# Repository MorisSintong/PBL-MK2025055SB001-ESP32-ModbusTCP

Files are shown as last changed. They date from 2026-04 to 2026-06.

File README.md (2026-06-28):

# PBL-MK2025055SB001 - Face Detection & Assembly Station SCADA

Project-Based Learning (PBL) repository for a SCADA prototype built around the
**Assembly Station** at Politeknik Negeri Batam (POLIBATAM). The system uses an
**ESP32** and a **Mitsubishi FX5U PLC** as the main components, communicating
over **Modbus TCP/IP** through a W5500 Ethernet module, with a PC-based face
recognition interface acting as the human-machine interface (HMI) and access
controller.

The main objective is to develop an automatic control & monitoring system for
the Assembly Station that:

- Can be accessed over **Wi-Fi** by external devices (PC, mobile, HMI).
- Talks to the **FX5U PLC** via **Modbus TCP/IP** through the ESP32 (Modbus
  server on port 503).
- Performs **face recognition** on the PC (OpenCV/LBPH) and only allows
  authorized operators to start the machine.
- Provides a web HMI with live video feed, status indicators, and start/stop/
  emergency/reset controls.

## Repository Layout

| Path | Description |
| --- | --- |
| `Electrical-Schematics/` | KiCad project and rendered images of the electrical wiring (ESP32 + W5500 + PLC I/O). |
| `ESP32-Program/` | PlatformIO firmware for the ESP32-S3 (Wi-Fi + Ethernet + Modbus TCP server). |
| `Interface/` | Python (Flask + OpenCV) face-recognition HMI and the web/HTML front-end. |
| `README.md` | High-level block diagram of the whole system. |

## System Architecture
```mermaid
graph TD
    Camera[Camera]
    PC[PC]
    PLC[PLC FX5U]
    Wago[Wago I/O Module]
    ExternalDevice[External Device]
    Output[Output]

    subgraph ESP32Container [ESP-32 Physical Device]
        ESP32Core(ESP-32)
        subgraph HostedServices [Hosted Services]
            WebServer[Web Server]
        end
    end

    Camera ---|USB-Serial| PC
    PC ---|HTTP Wi-Fi| ESP32Core
    Wago --- Output

    PLC ===|Modbus TCP/IP PLC=Client, ESP-32=Server| ESP32Core
    PLC ===|Modbus TCP/IP PLC=Client, Wago=Server| Wago

    WebServer -.->|Wi-Fi| ExternalDevice
```

## System Overview

1. **Interface (PC)** runs a Flask web app (`Interface/app.py`) that:
   - Captures the webcam feed and detects faces using Haar cascade.
   - Recognizes the operator using an LBPH model (`trainer/trainer.yml`).
   - On authorized detection, sends HTTP commands to the ESP32
     (`/action?type=start|stop|emergency|reset`).
2. **ESP32** (`ESP32-Program/src/main.cpp`) runs two FreeRTOS tasks:
   - **Core 0** – Wi-Fi + WebServer (receives commands from the PC interface).
   - **Core 1** – W5500 Ethernet + Modbus TCP server (port 503) that writes the
     command coils read by the FX5U PLC and reads status coils from the PLC.
3. **Mitsubishi FX5U PLC** is the Modbus TCP client that controls the Assembly
   Station actuators based on the ESP32 coils.

See the [System Architecture](#system-architecture) section for the full block diagram and the per-directory
`README.md` files for component-level details.

## Quick Start

1. Build and flash the firmware with PlatformIO:
   ```bash
   cd ESP32-Program
   pio run -t upload
   ```
2. Train the face model from the PC interface:
   ```bash
   cd Interface
   python 01_Ambil_Wajah.py   # capture dataset
   python 02_training.py      # train -> trainer/trainer.yml
   ```
3. Launch the web HMI:
   ```bash
   python app.py              # http://<PC-IP>:5000
   ```
4. Configure the PLC (FX5U) Modbus TCP client to connect to the ESP32 Ethernet
   IP (`192.168.1.50:503`) and read/write the coils listed in
   `ESP32-Program/src/main.cpp`.

## Finieshed Product & Implementation
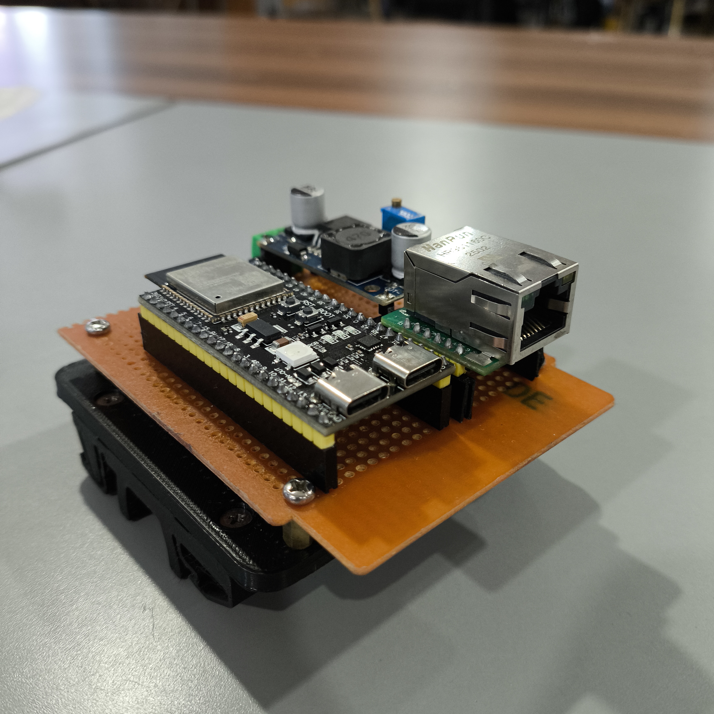
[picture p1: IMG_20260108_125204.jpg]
Finished PCB

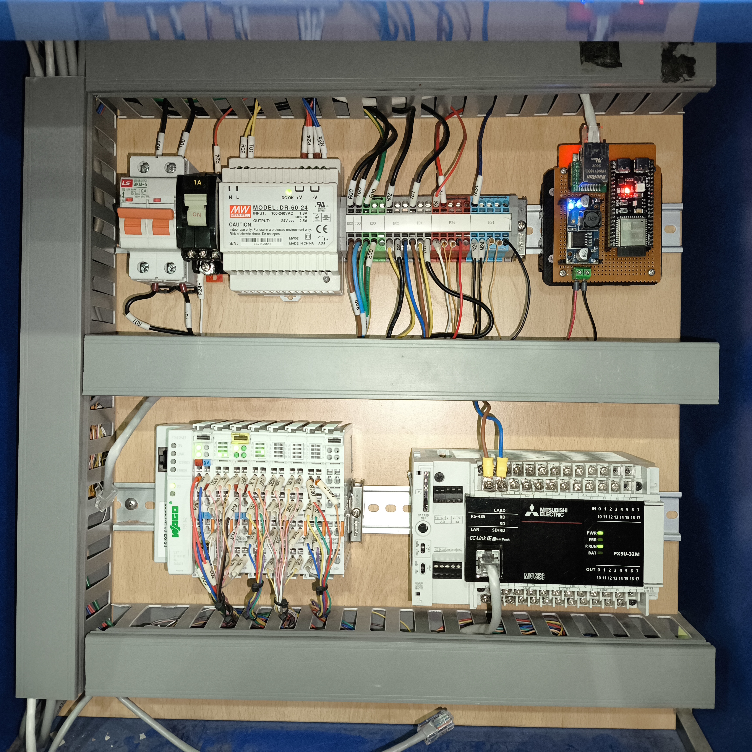
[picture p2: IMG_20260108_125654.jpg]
Implementation


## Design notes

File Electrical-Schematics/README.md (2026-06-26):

# Electrical-Schematics

This folder holds the electrical documentation for the PBL Assembly Station
control panel. It contains both the source KiCad project (editable) and the
exported/rendered images used in the report and README.

## Preview

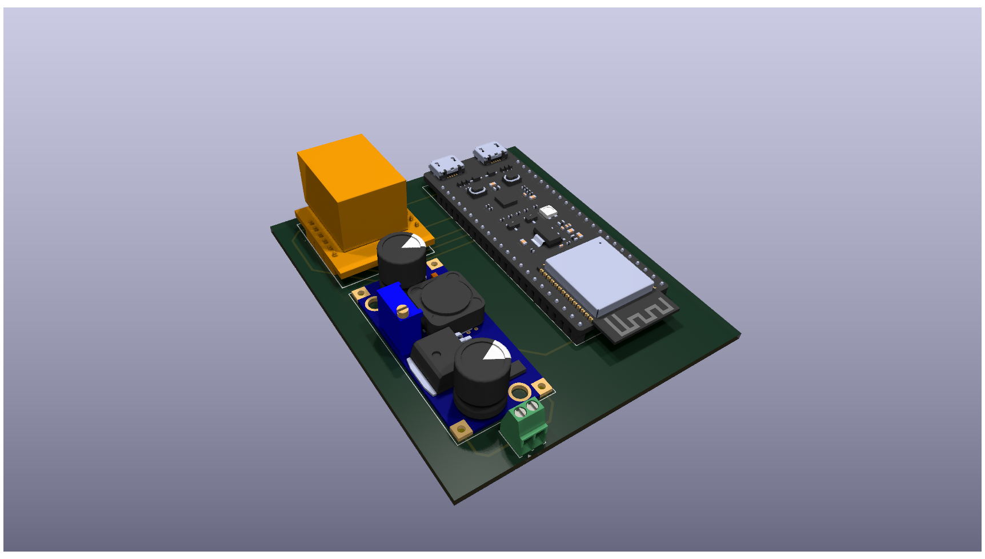
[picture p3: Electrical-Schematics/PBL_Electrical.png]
PBL Electrical


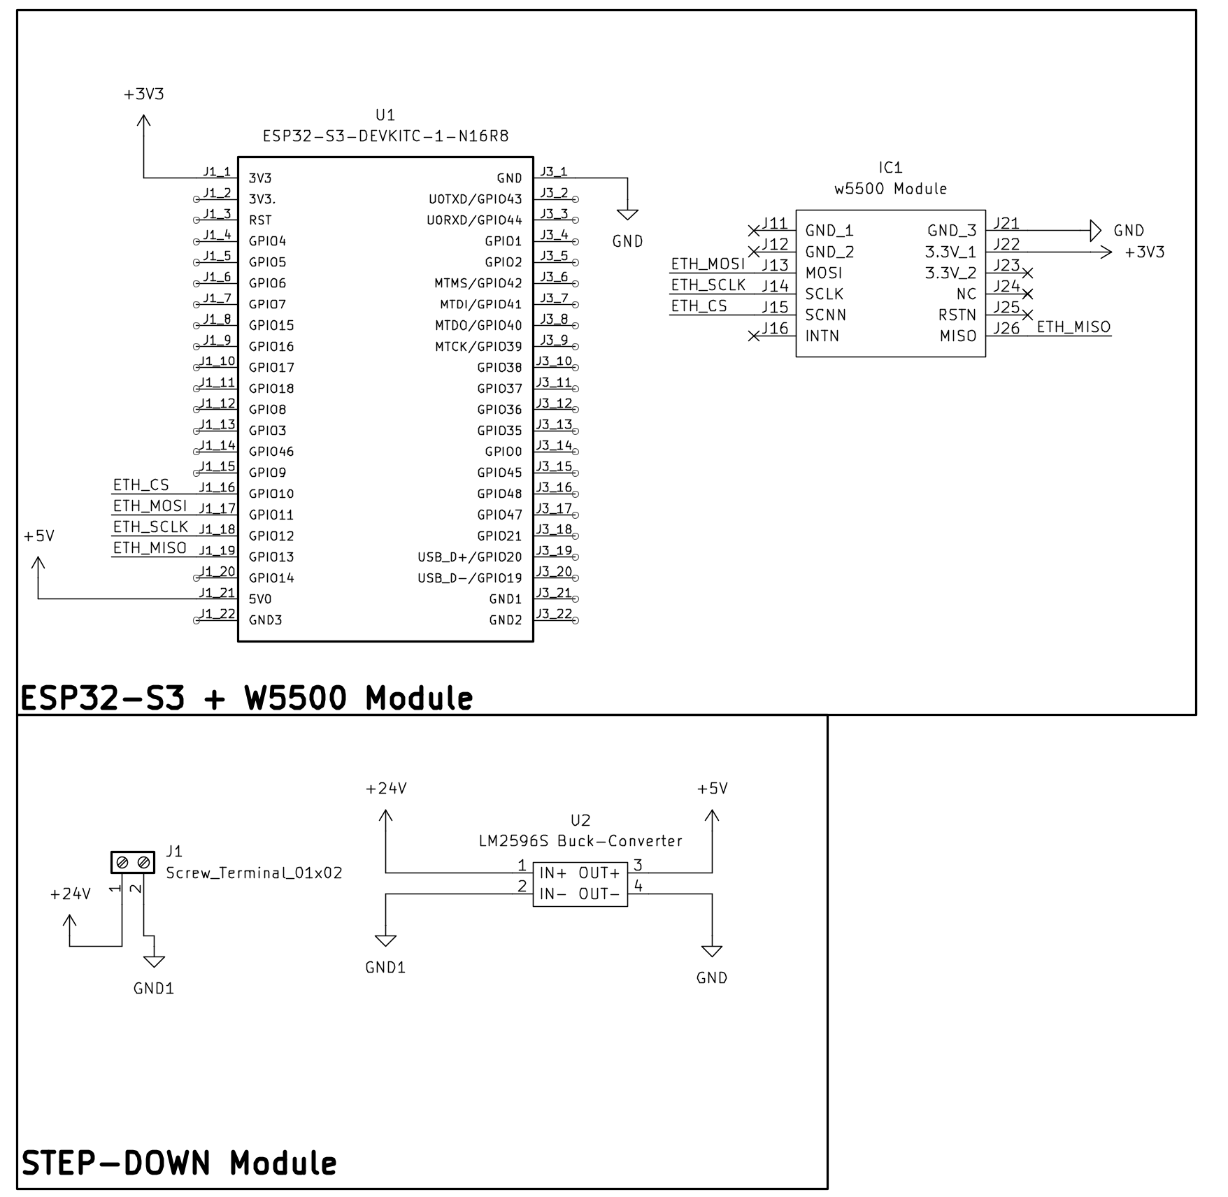
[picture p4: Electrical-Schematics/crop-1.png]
Crop 1


## Contents

- `PBL_Electrical.png` – Full rendered schematic/PCB image of the electrical
  wiring (ESP32-S3 + W5500 Ethernet module + PLC I/O + power supply).
- `crop-1.png` – Cropped close-up of a section of the schematic used in
  documentation.
- `PBL_Electrical_KiCad/` – The full KiCad project (schematic, PCB, symbols,
  3D model, footprints). See its own `README.md` for details.

## What it represents

The schematic wires:

- **ESP32-S3 DevKit** to the **W5500** over SPI (CS=10, MOSI=11, SCLK=12,
  MISO=13) for the Modbus TCP Ethernet link to the FX5U PLC.
- Power supply / protection blocks for the ESP32 and the Ethernet module.
- I/O routing between the ESP32 coils and the PLC digital inputs/outputs.

Use this as the wiring reference when assembling or troubleshooting the
hardware. The same pin assignments must match those defined in
`ESP32-Program/src/main.cpp`.

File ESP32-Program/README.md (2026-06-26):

# ESP32-Program

PlatformIO firmware project for the **ESP32-S3 DevKitC-1**. The firmware turns
the ESP32 into a protocol bridge between the PC face-recognition interface and
the Mitsubishi FX5U PLC:

- **Wi-Fi (Core 0)** – runs a `WebServer` that receives HTTP commands from the
  Python HMI (`/action`, `/status`, `/user_detection`).
- **Ethernet + Modbus TCP (Core 1)** – drives a W5500 module over SPI and runs
  a Modbus TCP server on **port 503** that the FX5U PLC reads/writes.

## Structure

- `platformio.ini` – PlatformIO configuration (board `esp32-s3-devkitc-1`,
  Arduino framework, PSRAM enabled, libraries: `Ethernet_Generic`,
  `modbus-esp8266`).
- `src/` – Application source code (`main.cpp`).
- `include/` – Project header files (currently empty/PlatformIO default).
- `lib/` – Project-specific (private) libraries (currently empty).
- `test/` – PlatformIO unit tests (currently empty).

## Build & flash

```bash
pio run -t upload
pio device monitor   # 921600 baud
```

## Modbus coil map (defined in `src/main.cpp`)

| Coil | Address | Direction | Description |
| --- | --- | --- | --- |
| BTN 1 (Start) | 112 | PC -> PLC | Momentary start command |
| BTN 2 (Stop) | 113 | PC -> PLC | Momentary stop command |
| BTN 3 (Emergency)| 114 | PC -> PLC | Momentary emergency command |
| BTN 4 (Reset) | 115 | PC -> PLC | Momentary reset command |
| User Detected | 116 | PC -> PLC | Face-recognition authorized flag |
| STS_RUNNING | 208 | PLC -> PC | Machine running indicator |
| STS_STOPPED | 209 | PLC -> PC | Machine stopped indicator |
| STS_EMG | 210 | PLC -> PC | Emergency active indicator |

Default Ethernet IP: `192.168.1.50`. Wi-Fi IP is configured statically inside
`main.cpp` (default `10.251.64.200`) – change these to match your network.

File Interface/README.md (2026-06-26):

# Interface

PC-side HMI and face-recognition application. The interface is written in
Python (Flask + OpenCV) and provides:

- A browser-based HMI with the live webcam feed, start/stop/emergency/reset
  buttons, and PLC status indicators.
- Face **detection** (Haar cascade) and **recognition** (LBPH) to authorize
  operators before the machine can be started.
- HTTP communication with the ESP32 web server to forward commands to the PLC.
- CSV timing logs for performance measurement.

## Main scripts

| File | Purpose |
| --- | --- |
| `app.py` | Primary Flask web HMI: video feed, face recognition, training, registration, PLC command forwarding. **Run this for the production interface.** |
| `AppImproved.py` | Performance-optimized variant of `app.py` (threaded `VideoStream`, lower JPEG quality, etc.). |
| `main.py` | Standalone Tkinter desktop GUI version of the HMI (no browser needed). |
| `pythonUDP.py` | Experimental variant that sends commands to the ESP32 over UDP instead of HTTP. |
| `01_Ambil_Wajah.py` | CLI tool to capture face images into `dataset/` for a given user ID. |
| `02_training.py` | CLI tool to train the LBPH model from `dataset/` into `trainer/trainer.yml`. |
| `test_modbus.py` | Standalone Modbus TCP client test to verify the ESP32 coils (connects to `192.168.1.50:503`). |

## Subdirectories

- `templates/` – Jinja2 HTML templates for the Flask HMI.
- `GUI/` – Stand-alone Arduino sketch (`GUI_REAL.ino`) for an early prototype
  that put the web HMI directly on a second ESP32.
- `dataset/` – Captured face images (`User.<id>.<n>.jpg`).
- `trainer/` – Trained LBPH model (`trainer.yml`).
- `Timings_log/` – Recorded timing CSVs from earlier test runs.

## Running

```bash
# 1. Capture faces (optional, or use the web HMI registration button)
python 01_Ambil_Wajah.py
# 2. Train the model
python 02_training.py
# 3. Launch the web HMI
python app.py          # open http://<PC-IP>:5000
```

Make sure the ESP32 IP inside each script matches the ESP32's actual Wi-Fi IP
(`ESP32_IP = "http://<IP>"`).

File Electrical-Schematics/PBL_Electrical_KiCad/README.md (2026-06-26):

# PBL_Electrical_KiCad

Native KiCad project for the PBL Assembly Station electrical schematic and PCB.

## Preview

PBL Electrical

## Key files

- `PBL_Electrical.kicad_pro` – KiCad project file (open this in KiCad).
- `PBL_Electrical.kicad_sch` – Schematic sheet.
- `PBL_Electrical.kicad_pcb` – PCB layout.
- `PBL_Electrical.kicad_prl` – KiCad project local settings.
- `PBL_Proj.bak` / `PBL_Proj-sem5.pretty/` / `PBL_Proj.kicad_sym` – Project
  symbol library, custom footprint library, and backups.
- `fp-info-cache`, `fp-lib-table`, `sym-lib-table` – KiCad library tables.
- `PBL_Electrical.png` – Rendered preview of the board/schematic.
- `PBL_Electrical.step` / `PBL_Electrical.wrl` – 3D model exports for CAD.
- `3d.pcb3d` – KiCad 3D viewer cache.
- `PBL_Electrical-backups/` – Automatic KiCad backups.

## How to use

1. Open `PBL_Electrical.kicad_pro` in **KiCad 6+**.
2. Edit the schematic / PCB as needed.
3. Re-export `PBL_Electrical.png` and the 3D models, then update the parent
   `Electrical-Schematics/` images if the wiring changes.

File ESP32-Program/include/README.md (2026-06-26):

# include

Reserved for project-wide C/C++ header files (`.h`) shared across the source
files in `../src`. Currently empty (no extra headers needed); the firmware in
`src/main.cpp` only includes library headers at this time.

PlatformIO automatically adds this directory to the include path, so any
header placed here can be included as `#include "myheader.h"`.

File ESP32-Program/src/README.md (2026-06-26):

# src

Main application source for the ESP32 firmware.

## Files

- `main.cpp` – The complete firmware entry point. It:
  - Initializes SPI for the W5500 Ethernet module and starts a Modbus TCP
    server on port 503.
  - Spawns two pinned FreeRTOS tasks:
    - `modbusTask` (Core 1, priority 2) – poll Modbus, process command flags,
      handle momentary coil timers, monitor W5500 socket/Ethernet link.
    - `wifiTask` (Core 0, priority 1) – connect to Wi-Fi with a static IP,
      start mDNS (`esp32-server.local`), serve the HTTP endpoints used by the
      PC interface, and auto-reconnect on Wi-Fi loss.
  - Exposes HTTP endpoints: `/`, `/status`, `/action?type=...`,
    `/user_detection?detected=1|0`.
  - Uses `std::atomic` flags + a Serial mutex for safe cross-core access.
- `src.7z` – Archive backup of previous source revisions.

To rebuild, run `pio run -t upload` from the parent `ESP32-Program/` directory.

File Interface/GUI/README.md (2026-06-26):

# GUI

Early-prototype GUI option that hosts a minimal web interface directly on a
separate ESP32 (instead of on the PC). Kept for reference/history.

## Contents

- `GUI_REAL/` – Arduino sketch (`GUI_REAL.ino`) that creates a Wi-Fi AP named
  `MEKAPBL` with password `mekagui1` and exposes `/action?type=...`
  endpoints to print `start` / `stop` / `emergency` / `reset` to the serial
  monitor (placeholder for driving relays/LEDs). See its `README.md`.

This prototype was later replaced by the PC-side Flask HMI in the parent
`Interface/` directory (`app.py`), which also performs face recognition.

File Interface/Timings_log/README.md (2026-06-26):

# Timings_log

Archived timing measurements from earlier interface/ESP32 round-trip tests.
Each CSV records `timestamp, source, command, duration_ms, success,
internal_latency_us` rows produced by the `_log_timing_csv` helper in the
interface scripts.

## Files

- `timings.csv` – General run log (default output path used by the scripts).
- `timings1.csv`, `timings2.csv` – Additional runs captured during testing.
- `timings_Jauh.csv` – Tests performed with a larger physical distance between
  the PC/ESP32 and the PLC (latency under range/relay conditions).

These files are kept for reference and for plotting performance in the project
report. New runs will recreate `timings.csv` in the `Interface/` working
directory unless the `_csv_path` variable is changed inside the scripts.

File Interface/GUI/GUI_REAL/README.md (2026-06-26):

# GUI_REAL

Arduino sketch for the early-prototype stand-alone ESP32 web HMI.

## `GUI_REAL.ino`

- Creates a Wi-Fi **Access Point** (`MEKAPBL` / `mekagui1`).
- Starts a `WebServer` on port 80 with the `/action?type=...` route.
- Accepts `start`, `stop`, `emergency`, `reset` commands and currently
  serial-prints the corresponding status (placeholder for driving
  relays/LEDs/actuators).
- Responds with `OK - <type>` on success or `Error` if the `type` argument is
  missing.

This was an initial feasibility prototype. The final system instead runs the
HMI on the PC (`Interface/app.py`) and uses this ESP32 only for face-gated
command forwarding; the production firmware lives in `ESP32-Program/`.

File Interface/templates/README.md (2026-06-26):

# templates

Jinja2 HTML templates rendered by the Flask HMI in the parent `Interface/`
directory.

## Files

- `index.html` – Single-page HMI shown to the operator. It contains:
  - An MJPEG `<img>` element pointing at `/video_feed` for the live webcam
    stream with face-detection overlays.
  - A colored status bar (Access Granted / Denied / System Stop).
  - Start / Stop / Emergency / Reset control buttons that issue fetch
    requests to the Flask routes (`/command/<cmd>`).
  - A poller to `/check_status` that updates PLC running/stopped/emergency
    indicators and the connection state.
  - Operator registration & model-training UI.

This file is served by the `/` route in `app.py` / `AppImproved.py`.

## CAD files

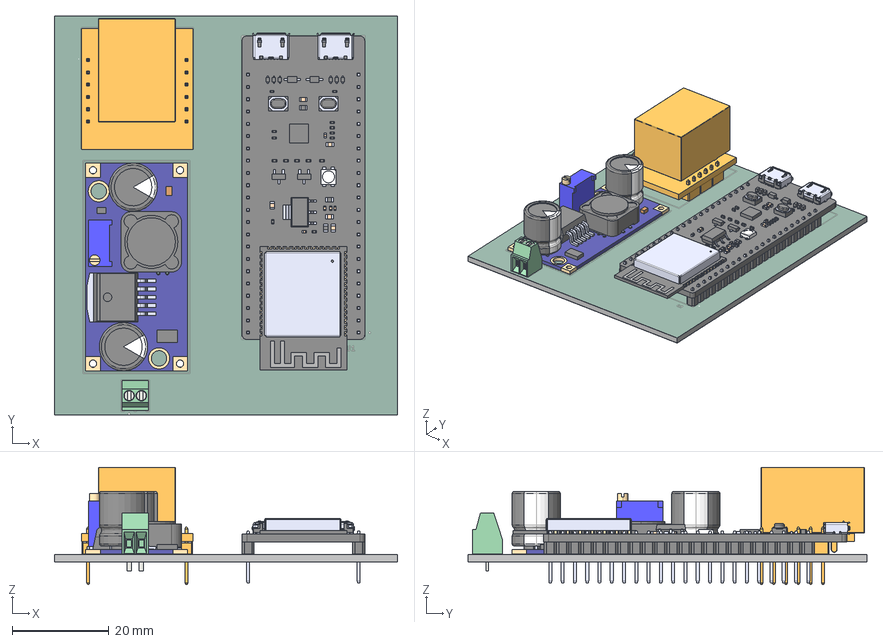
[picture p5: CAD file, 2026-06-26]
Electrical-Schematics/PBL_Electrical_KiCad/PBL_Electrical.step
71.0 x 82.5 x 24.3 mm
MC00100
3296W-1-104
DR125-331-R
EEUTA1V221 x 2
LM2596DSADJG
ESP32-S3-DEVKITC-1-N8R8
TerminalBlock_Phoenix_MPT-0,5-2-2.54_1x02_P2.54mm_Horizontal
WIZ850IO
PBL_Electrical_copper
PBL_Electrical_pad
PBL_Electrical_via
PBL_Electrical_silkscreen
PBL_Electrical_soldermask x 2
PBL_Electrical_PCB

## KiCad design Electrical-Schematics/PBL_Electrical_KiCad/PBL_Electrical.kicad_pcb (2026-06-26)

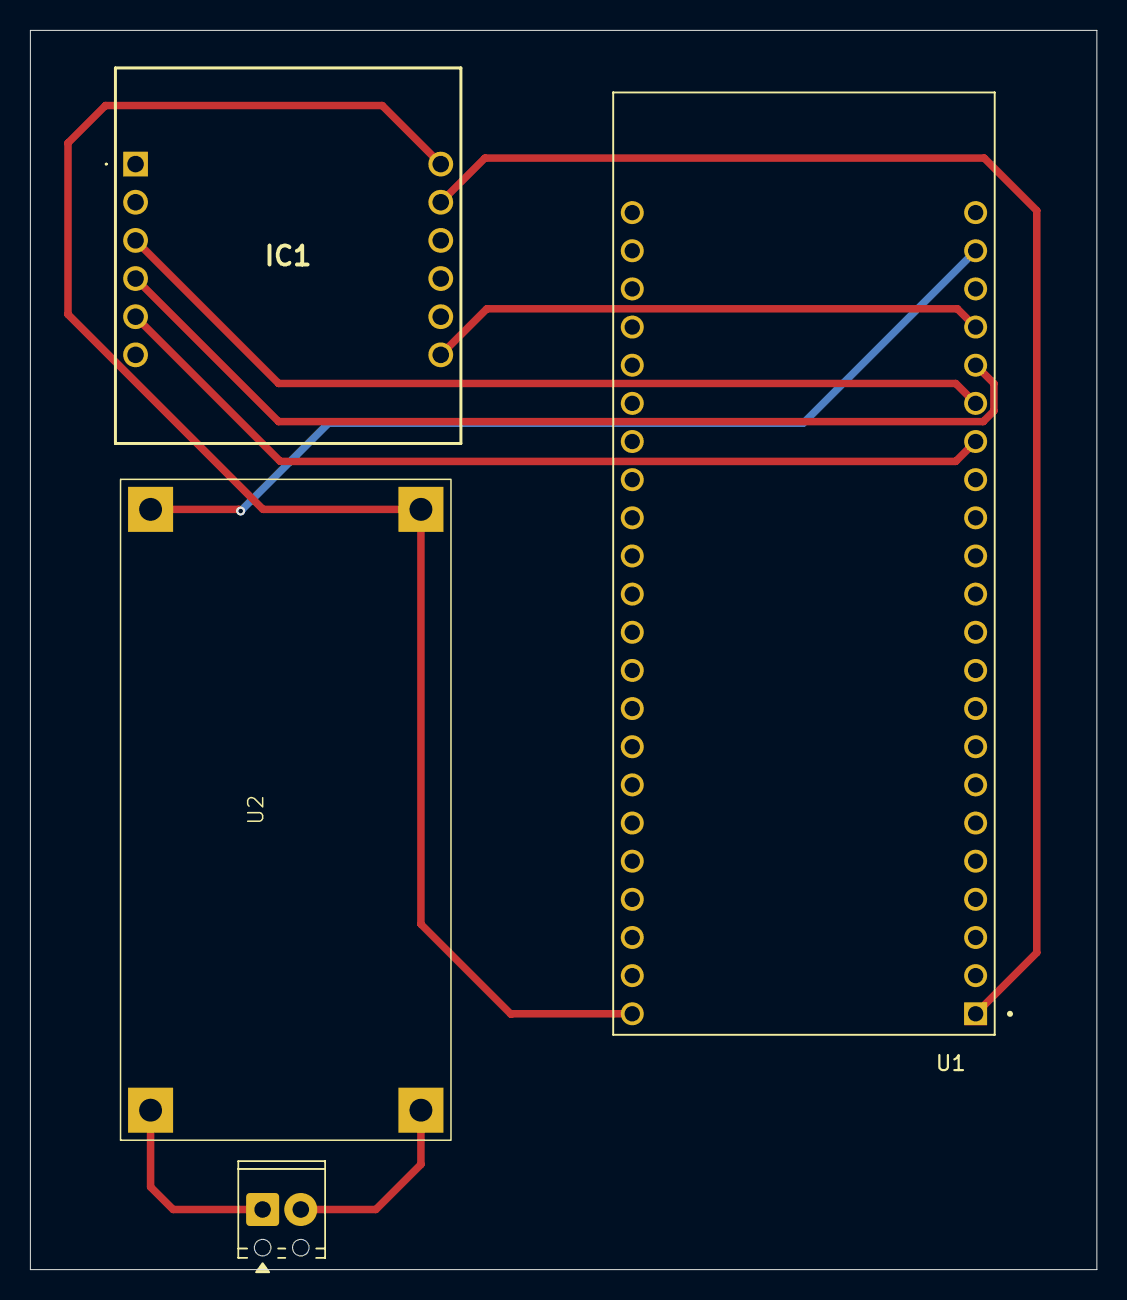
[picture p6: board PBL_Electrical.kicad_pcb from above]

Board: 2 copper layers, 71.0 x 82.5 mm, 4 parts (0 on the bottom side), 9 nets.

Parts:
IC1: w5500 Module; WIZ850IO
J1: Screw_Terminal_01x02; TerminalBlock_Phoenix_MPT-0,5-2-2.54_1x02_P2.54mm_Horizontal
U1: ESP32-S3-DEVKITC-1-N16R8; ESP32-S3-DEVKITC-1-N8R8
U2: LM2586S Buck-Converter; Untitled

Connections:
+3V3: IC1.J22 (3.3V_1), U1.J1_1 (3V3)
+5V: U1.J1_21 (5V0), U2.3 (OUT+)
+24V: J1.1, U2.1 (IN+)
/ETH_CS: IC1.J15 (SCNN), U1.J1_16 (GPIO10)
/ETH_MISO: IC1.J26 (MISO), U1.J1_19 (GPIO13)
/ETH_MOSI: IC1.J13 (MOSI), U1.J1_17 (GPIO11)
/ETH_SCLK: IC1.J14 (SCLK), U1.J1_18 (GPIO12)
GND: IC1.J21 (GND_3), U1.J3_1 (GND), U2.4 (OUT-)
GND1: J1.2, U2.2 (IN-)

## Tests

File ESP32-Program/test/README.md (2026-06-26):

# test

Reserved for PlatformIO unit tests for the ESP32 firmware. Tests placed here
(e.g. `test/test_main.cpp`) are run with `pio test` on the target hardware or
under a native simulator depending on the environment configuration.

Currently empty – no automated tests have been written yet. Manual validation
is performed through the serial monitor and the `test_modbus.py` script in the
`Interface/` directory.

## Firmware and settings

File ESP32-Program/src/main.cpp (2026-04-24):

#include <Arduino.h>
#include <WiFi.h>
#include <ESPmDNS.h>
#include <WebServer.h>
#include <SPI.h>
#include <Ethernet_Generic.h>
#include <ModbusEthernet.h>
#include <atomic> // REQUIRED for thread safety



// =======================================================================
// USER CONFIGURATION
// =======================================================================

const char* ssid = "TestEsp32";
const char* password = "12345678";

// W5500 Pins
constexpr uint8_t ETH_CS_PIN = 10;
constexpr uint8_t ETH_MOSI_PIN = 11;
constexpr uint8_t ETH_SCLK_PIN = 12;
constexpr uint8_t ETH_MISO_PIN = 13;


// Ethernet Network Settings
// IMPORTANT: Use a unique MAC address to avoid ARP conflicts
byte macAddress[] = {0x02, 0xAB, 0xCD, 0x01, 0x02, 0x03};
IPAddress staticIp(192, 168, 1, 50);
IPAddress staticGateway(192, 168, 1, 1);
IPAddress staticSubnet(255, 255, 255, 0);
IPAddress staticDns(192, 168, 1, 1);

// Modbus Coils (Buttons)
const uint16_t COIL_BTN_1 = 112;
const uint16_t COIL_BTN_2 = 113;
const uint16_t COIL_BTN_3 = 114;
const uint16_t COIL_BTN_4 = 115;

// Modbus Coil (User Detection Status - Written by Face Recognition System)
const uint16_t COIL_USER_DETECTED = 116;

// Modbus Coils (Status Indicators - Read from PLC)
const uint16_t STS_RUNNING = 208;
const uint16_t STS_STOPPED = 209;
const uint16_t STS_EMG     = 210;

// Shared Variables (Atomic for thread safety)
std::atomic<bool> reqBtn1(false);
std::atomic<bool> reqBtn2(false);
std::atomic<bool> reqBtn3(false);
std::atomic<bool> reqReset(false);
std::atomic<unsigned long> actionStartTime(0);
std::atomic<unsigned long> lastInternalLatencyUs(0);

// User Detection Status (from Face Recognition System)
std::atomic<bool> userDetected(false);
std::atomic<bool> userDetectedChanged(false);

volatile unsigned long timerBtn1 = 0;
volatile unsigned long timerBtn2 = 0;
volatile unsigned long timerBtn3 = 0;
volatile unsigned long timerBtn4 = 0;
const unsigned long MOMENTARY_DELAY = 500; 

// Objects
WebServer server(80);
ModbusEthernet mb;
SemaphoreHandle_t serialMutex; // Mutex for Serial safety

// Modbus Activity Counters (for real tracking)
volatile uint32_t modbusConnections = 0;
volatile uint32_t modbusDisconnections = 0;

// Task Handles
TaskHandle_t ModbusTaskHandle;
TaskHandle_t WifiTaskHandle;

// Forward declaration for callbacks
void safePrintln(const String &msg);

// Modbus Callbacks
bool onModbusConnect(IPAddress ip) {
  modbusConnections++;
  Serial.print("[Modbus] >>> Client CONNECTED from: ");
  Serial.println(ip);
  return true;  // Accept connection
}

// Helper for safe printing
void safePrintln(const String &msg) {
  if (xSemaphoreTake(serialMutex, portMAX_DELAY)) {
    Serial.println(msg);
    xSemaphoreGive(serialMutex);
  }
}


// =======================================================================
// WEB SERVER FUNCTIONS (Run on Core 0) 
// =======================================================================

void handleRoot() {
  server.send(200, "text/plain", "ESP32 Opti-Server Online");
}

void handleStatus() {
  // Read Modbus Coils (Thread-safe enough for bool read)
  bool running = mb.Coil(STS_RUNNING);
  bool stopped = mb.Coil(STS_STOPPED);
  bool emg     = mb.Coil(STS_EMG);
  unsigned long lastLatency = lastInternalLatencyUs;

  String json = "{";
  json += "\"running\":" + String(running ? "true" : "false") + ",";
  json += "\"stopped\":" + String(stopped ? "true" : "false") + ",";
  json += "\"emergency\":" + String(emg ? "true" : "false") + ",";
  json += "\"last_internal_latency_us\":" + String(lastLatency);
  json += "}";

  server.send(200, "application/json", json);
}

void handleAction() {
  if (!server.hasArg("type")) {
    server.send(400, "text/plain", "Missing type");
    safePrintln("[Web] Error: Missing type argument");
    return;
  }
  String type = server.arg("type");
  safePrintln("[Web] Received command: " + type);
  
  // THREAD-SAFE FIX:
  // Instead of calling mb.Coil() directly (which is dangerous across cores),
  // we just set a flag. The Modbus Task (Core 1) will pick it up safely.
  
  actionStartTime = micros();

  if (type == "start") {
    reqBtn1 = true;
  } else if (type == "stop") {
    reqBtn2 = true;
  } else if (type == "emergency") {
    reqBtn3 = true;
  } else if (type == "reset") {
    reqReset = true;
  } else {
    server.send(400, "text/plain", "Unknown command");
    return;
  }
  server.send(200, "text/plain", "OK");
}

// Handler for User Detection Status from Face Recognition System
void handleUserDetection() {
  if (!server.hasArg("detected")) {
    server.send(400, "text/plain", "Missing detected parameter");
    return;
  }
  String detected = server.arg("detected");
  bool newState = (detected == "1" || detected == "true");
  
  // Only update if state changed
  if (userDetected != newState) {
    userDetected = newState;
    userDetectedChanged = true;
    safePrintln("[Web] User detection: " + String(newState ? "DETECTED" : "NOT DETECTED"));
  }
  
  server.send(200, "text/plain", "OK");
}

// =======================================================================
// FREERTOS TASKS
// =======================================================================

// Task 1: Modbus & Ethernet (High Priority, Core 1)
void modbusTask(void * parameter) {
  // Modbus is already initialized in setup() for faster response
  // This task just runs mb.task() in a loop

  safePrintln("[Core 1] Modbus task running");

  static unsigned long lastLinkCheck = 0;
  static unsigned long lastSocketCheck = 0;

  for (;;) {
    // 0. Check Ethernet Link and Socket Status
    if (millis() - lastLinkCheck > 2000) {
        lastLinkCheck = millis();
        EthernetLinkStatus linkStatus = Ethernet.linkStatus();
        if (linkStatus == LinkOFF) {
             safePrintln("[Core 1] !!! Ethernet Link OFF !!!");
        } else if (linkStatus == Unknown) {
             safePrintln("[Core 1] Ethernet Link: Unknown");
        }
    }
    
    // 0b. Monitor Modbus Connections and W5500 Socket Status
    if (millis() - lastSocketCheck > 3000) {
        lastSocketCheck = millis();
        Ethernet.maintain(); // Force socket cleanup
        
        // Report actual Modbus TCP connections
        safePrintln("[Core 1] Connections: " + String(modbusConnections) + " | Link: " + 
                   (Ethernet.linkStatus() == LinkON ? "ON" : "OFF"));
        
        // Print W5500 socket status for debugging
        Serial.print("[W5500 Sockets] ");
        for (int i = 0; i < 8; i++) {
            uint8_t status = W5100.readSnSR(i);
            Serial.print(i);
            Serial.print(":");
            Serial.print(status, HEX);
            Serial.print(" ");
        }
        Serial.println();
    }
    // 1. PROCESS FLAGS (Thread-Safe Write)
    if (reqBtn1) {
      mb.Coil(COIL_BTN_1, true);
      timerBtn1 = millis();
      reqBtn1 = false;
      unsigned long latency = micros() - actionStartTime;
      lastInternalLatencyUs.store(latency);
      safePrintln("BTN 1 Triggered. Latency: " + String(latency) + " us");
    }
    if (reqBtn2) {
      mb.Coil(COIL_BTN_2, true);
      timerBtn2 = millis();
      reqBtn2 = false;
      unsigned long latency = micros() - actionStartTime;
      lastInternalLatencyUs.store(latency);
      safePrintln("BTN 2 Triggered. Latency: " + String(latency) + " us");
    }
    if (reqBtn3) {
      mb.Coil(COIL_BTN_3, true);
      timerBtn3 = millis();
      reqBtn3 = false;
      unsigned long latency = micros() - actionStartTime;
      lastInternalLatencyUs.store(latency);
      safePrintln("BTN 3 Triggered. Latency: " + String(latency) + " us");
    }
    if (reqReset) {
      mb.Coil(COIL_BTN_4, true);
      timerBtn4 = millis();
      reqReset = false;
      unsigned long latency = micros() - actionStartTime;
      lastInternalLatencyUs.store(latency);
      safePrintln("Reset Triggered. Latency: " + String(latency) + " us");
    }

    // 1b. PROCESS USER DETECTION (Continuous coil, not momentary)
    if (userDetectedChanged) {
      bool detected = userDetected.load();
      mb.Coil(COIL_USER_DETECTED, detected);
      userDetectedChanged = false;
      safePrintln("User Detection Coil: " + String(detected ? "HIGH" : "LOW"));
    }

    // 2. Run Modbus Task
    mb.task();

    // 3. Handle Timers
    unsigned long now = millis();
    if (timerBtn1 > 0 && now - timerBtn1 > MOMENTARY_DELAY) {
      mb.Coil(COIL_BTN_1, false);
      timerBtn1 = 0;
    }
    if (timerBtn2 > 0 && now - timerBtn2 > MOMENTARY_DELAY) {
      mb.Coil(COIL_BTN_2, false);
      timerBtn2 = 0;
    }
    if (timerBtn3 > 0 && now - timerBtn3 > MOMENTARY_DELAY) {
      mb.Coil(COIL_BTN_3, false);
      timerBtn3 = 0;
    }
    if (timerBtn4 > 0 && now - timerBtn4 > MOMENTARY_DELAY) {
      mb.Coil(COIL_BTN_4, false);
      timerBtn4 = 0;
    }

    // Small yield
    vTaskDelay(1 / portTICK_PERIOD_MS); 
  }
}

// Task 2: Wi-Fi & Web Server (Lower Priority, Core 0)
void wifiTask(void * parameter) {
  safePrintln("[Core 0] Wi-Fi Task Started");
  
  // OPTIMIZATION: Disable Power Save for low latency HTTP response
  WiFi.setSleep(false);
  
  // --- STATIC IP CONFIGURATION ---
  // Must be called BEFORE WiFi.begin()
  IPAddress wifiIp(10, 251, 64, 200);       
  IPAddress wifiGateway(10, 251, 64, 8);
  IPAddress wifiSubnet(255, 255, 255, 0);
  IPAddress wifiDns(10, 251, 64, 8);
  
  if (!WiFi.config(wifiIp, wifiGateway, wifiSubnet, wifiDns)) {
    safePrintln("[Core 0] Error: Failed to configure Static IP!");
  }
  // ------------------------------------

  WiFi.begin(ssid, password);
  while (WiFi.status() != WL_CONNECTED) {
    Serial.print(".");
    vTaskDelay(500 / portTICK_PERIOD_MS);
  }
  Serial.println("");

  safePrintln("[Core 0] Wi-Fi IP: " + WiFi.localIP().toString());

  if (MDNS.begin("esp32-server")) {
    safePrintln("[Core 0] mDNS responder started: http://esp32-server.local");
  }

  server.on("/", handleRoot);
  server.on("/status", handleStatus); // New Endpoint
  server.on("/action", handleAction);
  server.on("/user_detection", handleUserDetection); // User Detection from Face Recognition
  server.begin();

  static unsigned long lastWifiCheck = 0;

  for (;;) {
    server.handleClient();
    
    // Auto Reconnect Logic (Non-blocking)
    if (millis() - lastWifiCheck > 10000) {
      lastWifiCheck = millis();
      if (WiFi.status() != WL_CONNECTED) {
        safePrintln("[Core 0] Wi-Fi lost. Reconnecting...");
        WiFi.disconnect();
        WiFi.reconnect();
      }
    }

    // Yield to let the OS handle background Wi-Fi stack
    vTaskDelay(2 / portTICK_PERIOD_MS);
  }
}

// =======================================================================
// MAIN SETUP
// =======================================================================

void setup() {
  // OPTIMIZATION: Force 240MHz
   setCpuFrequencyMhz(240); // DISABLED: Causes W5500 Instability
  
  Serial.begin(921600);
  while(!Serial) delay(10);

  // Create Mutex for Serial
  serialMutex = xSemaphoreCreateMutex();

  safePrintln("System Booting...");

  // Initialize Ethernet HERE (Main Thread) to avoid SPI conflicts
  SPI.begin(ETH_SCLK_PIN, ETH_MISO_PIN, ETH_MOSI_PIN);
  SPI.setFrequency(8000000); // Reduced to 8MHz for maximum stability in multi-device networks
  Ethernet.init(ETH_CS_PIN);
  
  // Socket timeout configuration for W5500 (helps with multi-device networks)
  Ethernet.setRetransmissionTimeout(200);  // 200ms timeout (default is 200)
  Ethernet.setRetransmissionCount(4);      // 4 retries (default is 8)
  
  Ethernet.begin(macAddress, staticIp, staticDns, staticGateway, staticSubnet);
  safePrintln("Ethernet IP: " + Ethernet.localIP().toString());
  safePrintln("Ethernet MAC: 02:AB:CD:01:02:03");

  // CRITICAL: Initialize Modbus server HERE in setup() so it's ready IMMEDIATELY
  // This ensures the server is listening BEFORE any PLC connection attempts
  mb.onConnect(onModbusConnect);
  mb.server(503);
  mb.addCoil(0, false, 300); 
  mb.addHreg(0, 0, 300);
  safePrintln("Modbus TCP Server initialized on port 503");

  // Create Task for Modbus (Core 1)
  xTaskCreatePinnedToCore(
    modbusTask,       // Function
    "ModbusTask",     // Name
    8192,             // Stack size (Bytes)
    NULL,             // Param
    2,                // Priority (Higher = 2)
    &ModbusTaskHandle,// Handle
    1                 // Core ID (1 = App Core)
  );

  // Create Task for Wi-Fi (Core 0)
  xTaskCreatePinnedToCore(
    wifiTask,         // Function
    "WifiTask",       // Name
    8192,             // Stack size
    NULL,             // Param
    1,                // Priority (Lower = 1)
    &WifiTaskHandle,  // Handle
    0                 // Core ID (0 = Pro Core)
  );
}

void loop() {
  // Main loop is empty because tasks handle everything.
  // We can delete the setup task to free memory.
  vTaskDelete(NULL);
}

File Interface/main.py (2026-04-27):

import cv2
import requests
import tkinter as tk
from tkinter import messagebox
from PIL import Image, ImageTk
import time
import threading
import os
import sys
import csv
from datetime import datetime

# CSV logging
_csv_lock = threading.Lock()
_csv_path = 'timings.csv'

def _log_timing_csv(source, cmd, duration_ms, success):
    header = ['timestamp', 'source', 'command', 'duration_ms', 'success', 'internal_latency_us']
    row = [datetime.utcnow().isoformat(timespec='milliseconds') + 'Z', source, cmd, '' if duration_ms is None else f"{duration_ms:.2f}", str(bool(success)), '']
    with _csv_lock:
        write_header = False
        if not os.path.exists(_csv_path):
            write_header = True
        with open(_csv_path, 'a', newline='') as f:
            writer = csv.writer(f)
            if write_header:
                writer.writerow(header)
            writer.writerow(row)

# --- KONFIGURASI ---
ESP32_IP = "http://10.194.229.48"  

# Fix for cv2.data attribute error
if hasattr(cv2, 'data'):
    FACE_CASCADE_PATH = cv2.data.haarcascades + 'haarcascade_frontalface_default.xml'
else:
    # Fallback 1: Inside cv2 package
    FACE_CASCADE_PATH = os.path.join(os.path.dirname(cv2.__file__), 'data', 'haarcascades', 'haarcascade_frontalface_default.xml')
    
    # Fallback 2: Conda Windows path
    if not os.path.exists(FACE_CASCADE_PATH):
        FACE_CASCADE_PATH = os.path.join(sys.prefix, 'Library', 'etc', 'haarcascades', 'haarcascade_frontalface_default.xml')

class FaceControlApp:
    def __init__(self, window):
        self.window = window
        self.window.title("SISTEM KONTROL - POLIBATAM (FINAL)")
        self.window.geometry("900x750")
        self.window.configure(bg="#1a1a1d")

        # Load AI
        self.face_cascade = cv2.CascadeClassifier(FACE_CASCADE_PATH)
        self.recognizer = cv2.face.LBPHFaceRecognizer_create()
        
        if os.path.exists('trainer/trainer.yml'):
            self.recognizer.read('trainer/trainer.yml')
            print("Model Trainer dimuat.")
        else:
            messagebox.showerror("Error", "File trainer/trainer.yml tidak ditemukan!")
            return

        self.cap = None
        self.is_camera_on = False
        self.is_authorized = False
        self.is_emergency_active = False 
        
        # --- GUI LAYOUT ---
        tk.Label(window, text="MK202505SB001 - PROCESSING SYSTEM", font=("Arial", 20, "bold"), bg="#1a1a1d", fg="white").pack(pady=10)

        # Frame Video
        self.video_frame = tk.Label(window, bg="black", width=85, height=20, relief="sunken", bd=2)
        self.video_frame.pack(pady=5)

        # Status Bar
        self.status_label = tk.Label(window, text="SISTEM STANDBY - SILAKAN BUKA KAMERA", font=("Courier", 14, "bold"), bg="#333", fg="white", width=60, height=2)
        self.status_label.pack(pady=10)

        # Tombol BUKA KAMERA
        self.btn_open_cam = tk.Button(window, text="📷 BUKA KAMERA / SCAN WAJAH", bg="#007bff", fg="white", font=("Arial", 12, "bold"), 
                                      width=40, height=2, command=self.start_camera)
        self.btn_open_cam.pack(pady=5)

        # Frame Tombol Kontrol
        self.btn_frame = tk.Frame(window, bg="#1a1a1d")
        self.btn_frame.pack(pady=15)

        # Tombol-Tombol Mesin
        self.btn_start = self.create_button("START", "#28a745", self.cmd_start)
        self.btn_stop = self.create_button("STOP", "#dc3545", self.cmd_stop)
        self.btn_emg = self.create_button("EMERGENCY", "#ffc107", self.cmd_emg)
        self.btn_reset = self.create_button("RESET", "#6c757d", self.cmd_reset)

        # Pastikan Reset disabled di awal
        self.btn_reset.config(state="disabled") 

    def create_button(self, text, color, command):
        btn = tk.Button(self.btn_frame, text=text, bg=color, fg="white", font=("Arial", 11, "bold"), 
                        width=15, height=2, command=command, state="disabled")
        btn.pack(side="left", padx=10)
        return btn

    def start_camera(self):
        # Jika sedang Emergency, tolak akses buka kamera
        if self.is_emergency_active:
            messagebox.showwarning("PERINGATAN", "Sistem dalam Mode EMERGENCY!\nTekan tombol RESET terlebih dahulu.")
            return

        if not self.is_camera_on:
            self.cap = cv2.VideoCapture(0)
            self.is_camera_on = True
            self.btn_open_cam.config(text="TUTUP KAMERA", bg="#555")
            self.status_label.config(text="MEMINDAI WAJAH...", bg="#333", fg="yellow")
            self.update_video()
        else:
            self.stop_camera_logic()

    def stop_camera_logic(self):
        self.is_camera_on = False
        if self.cap:
            self.cap.release()
        self.video_frame.config(image='', bg="black", width=85, height=20) 
        self.btn_open_cam.config(text="📷 BUKA KAMERA / SCAN WAJAH", bg="#007bff")
        
        # Kunci sistem kembali
        self.lock_system()
        self.status_label.config(text="KAMERA MATI - SISTEM STOP", bg="#333", fg="white")

    def update_video(self):
        if self.is_camera_on and self.cap.isOpened():
            ret, frame = self.cap.read()
            if ret:
                gray = cv2.cvtColor(frame, cv2.COLOR_BGR2GRAY)
                faces = self.face_cascade.detectMultiScale(gray, 1.2, 5, minSize=(30, 30))

                for (x, y, w, h) in faces:
                    id, confidence = self.recognizer.predict(gray[y:y+h,x:x+w])
                    
                    if confidence < 60: 
                        detected_id = id
                        name = "OWNER (ACCESS GRANTED)"
                        color = (0, 255, 0)
                        self.unlock_system()
                    else:
                        name = "UNKNOWN"
                        color = (0, 0, 255)

                    cv2.rectangle(frame, (x, y), (x+w, y+h), color, 2)
                    cv2.putText(frame, str(name), (x+5, y-5), cv2.FONT_HERSHEY_SIMPLEX, 0.8, color, 2)

                if len(faces) == 0:
                    self.lock_system()

                img = cv2.cvtColor(frame, cv2.COLOR_BGR2RGB)
                img = Image.fromarray(img)
                img = img.resize((640, 360))
                imgtk = ImageTk.PhotoImage(image=img)
                self.video_frame.imgtk = imgtk
                self.video_frame.configure(image=imgtk, width=640, height=360)

            self.window.after(10, self.update_video)
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

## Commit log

2026-04-24 Initialize README with project description
    Added project overview and objectives for the SCADA system prototype.
2026-04-27 Menambahkan file Interface
    [timings.csv, timings1.csv, timings2.csv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]
2026-04-27 Add README for Modbus TCP/IP Bridge program
    Added a README file explaining the Modbus TCP/IP Bridge program for ESP32-S3.
2026-06-26 added detailed explanations
    [PBL_Electrical.kicad_pcb, PBL_Electrical.kicad_sch, PBL_Electrical.step]
2026-10-14 refactor(firmware): migrate ESP32 toolchain from PlatformIO to CMake, Ninja, and Just
    - Remove legacy PlatformIO configuration and monolithic main.cpp
    - Modularize firmware into App/Inc and App/Src (bridge_state, eth_driver, modbus_bridge, web_server, logger)
    - Implement lock-free atomic inter-core synchronization and latency tracking
    - Add dual-targeting CMake build system with Ninja support
    - Introduce host simulation unit test suite with CTest (BridgeState, ModbusCoils, RestApi)
    - Add justfile automation for building, testing, flashing (probe-rs / esptool), and monitoring
    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
2026-10-14 feat(emulation): add Renode controller and full multi-node system emulator with QoS benchmark
    - Add Renode .resc platform script and RenodeController in Emulation/
    - Add system_emulator.py implementing virtual ESP32 bridge, FX5U PLC, and HMI client
    - Automate multi-node QoS evaluation generating statistical summaries and timings_emulated.csv
    - Add just emulate-qos and just emulate-renode recipes to root justfile
2026-10-14 fix(firmware): harden FreeRTOS delays, atomic bitmasks, safe timers, and expand edge-case tests
    - Fix vTaskDelay tick calculation using pdMS_TO_TICKS(1) to prevent IDLE1 TWDT starvation
    - Pack PLC status indicators into std::atomic<uint8_t> bitmask to eliminate state tearing
    - Add struct PulseTimer with active flag preventing stuck coils when millis() == 0
    - Eliminate periodic heap allocations in EthernetDriver using fixed stack buffers
    - Add bounded Wi-Fi connection timeout (10s) in WebServerManager preventing boot freezes
    - Add CORS Access-Control-Allow-Origin headers to HTTP REST endpoints
    - Synchronize Wi-Fi static IP 10.251.64.200 across Interface/app.py and Interface/main.py
    - Expand C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
2026-10-17 feat(firmware): add native Xtensa ESP32-S3 CMake/Ninja toolchain, ROM linker script, and on-chip self-test
